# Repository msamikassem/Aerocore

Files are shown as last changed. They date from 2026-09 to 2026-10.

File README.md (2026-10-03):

# Aerocore — 3" Flight Controller

Aerocore is a flight controller for 3-inch FPV drones, built around an STM32F411 microcontroller and a BMI270 IMU. It handles IMU sensing, ESC motor control, USB configuration, and power regulation from a 4S LiPo on a single 4-layer board.

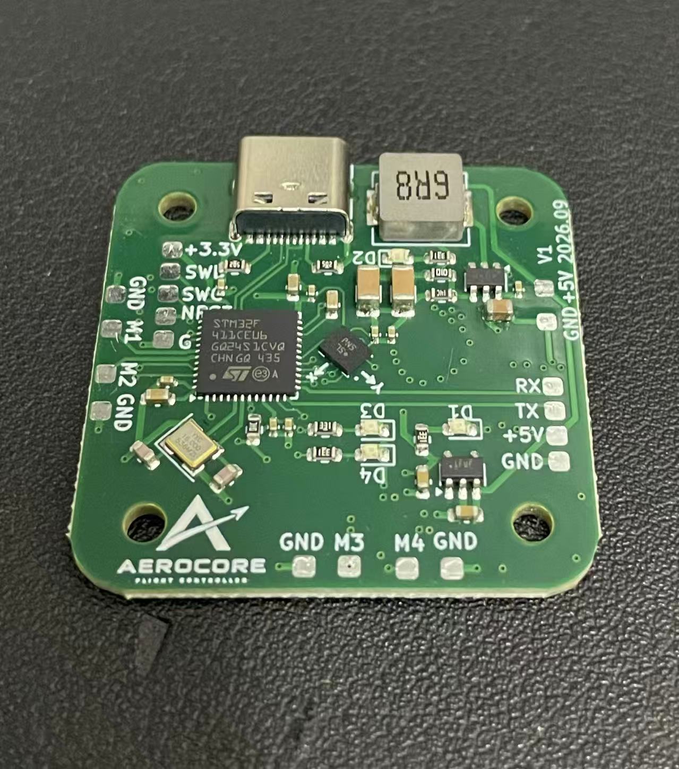
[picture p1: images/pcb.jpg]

## What it does

- Runs an STM32F411CEU6 (Cortex-M4, 100MHz) as the main flight computer
- BMI270 6-axis IMU over SPI for gyro/accel
- USB-C mainly for serial communication with a PC
- Powers itself from a 4S LiPo, steps down to 5V (buck) and 3.3V (LDO) on board
- Drives 4 ESCs via PWM 
- UART header for an ELRS receiver
- Dedicated ST-Link header for programming/debugging
- 2 status LEDs + 2 power LEDS (5v and 3v)

## Key specs

| | |
|---|---|
| MCU | STM32F411CEU6, 100MHz Cortex-M4, QFN48 |
| IMU | Bosch BMI270, SPI |
| Input power | 4S LiPo (up to 60A absolute max draw, 15A per motor) |
| Onboard rails | 5V (LMR51430 buck), 3.3V (TLV75533 LDO) |
| USB | USB-C, USB2.0 full-speed |
| Board | 4 layers, 36×36mm, 1.6mm thick |
| Stackup | JLC04161H-7628 (1oz outer / 0.5oz inner copper) |
| Mounting holes | 4× M2.5, 26.5×26.5mm spacing|

## Repo layout

```
hardware/                           -> PCB files
    kicad/                          -> the actual schematic + PCB source files (final version)
    Component/      
        Data_sheets/                -> Data sheets of chosen components 
        My_FootPrints.pretty/       -> FootPrints not avaliable on KiCAD
        Schematics/                 -> Schematics not avaliable on KiCAD
        3D part/                    -> Components' 3D model
    archive/                        -> PCB V1
    manufacturing/                  -> files needed by PCB manufacturer
        bom/                        -> bill of material
        cpl/                        -> component placement
        DRC/                        -> KiCAD Error and warning reports
    
firmware/                           -> flight firmware
docs/
    design-log                      -> PCB design decisions and difficulties
    specs                           -> PCB specifications  
```

## Status

- [X] Schematic design
- [X] PCB layout
- [X] Ordered from JLCPCB
- [X] Board assembled and bring-up tested
- [ ] Firmware
- [ ] First flight

## Tools used

- KiCad 7 for schematic + PCB

## License

MIT — see [LICENSE](LICENSE). Feel free to use any of this for your own projects; if you spot a mistake I haven't caught yet, I'd genuinely like to know.

## Author

Mohammed Kassem — built as a personal project. [msamikassem@gmail.com/ linkedin.com/in/msamikassem]

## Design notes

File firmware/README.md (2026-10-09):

# Firmware

Bare-metal firmware for the Aerocore flight controller using the STM32F411 and BMI270.

## Current Status

* STM32F411 project created.
* 16 MHz external crystal configured.
* PLL configured for 96 MHz system clock.
* APB1 configured to 48 MHz and APB2 to 96 MHz.
* PB3 LED tested at 96 MHz.
* ST-LINK working for flashing and debugging.
* SPI1 configured for the BMI270 (mode 0, 6 MHz).
* BMI270 CHIP_ID read successfully (0x24).
* BMI270 config file loaded.
* Accelerometer (±4g, 1600 Hz) and gyroscope (±250 dps, 3200 Hz) working.
* Raw and scaled (g and dps) values printed over USB-C.

## Planned Approach

* Bare-metal C to learn how the STM32 works at the register level.
* SPI1 for the BMI270.
* DMA for transferring data.
* TIM4 PWM for the 4 ESCs.
* USART2 for the ELRS receiver.
* USB-C for serial communication.
* Eventually add sensor fusion and basic flight control.

## Toolchain

* STM32CubeMX — used only to generate the initial project files.
* STM32CubeIDE — used to write, build, and debug the firmware.
* ARM GNU Toolchain — used to compile the firmware.
* ST-LINK — used to flash and debug the PCB.

## Tasks

**Clock**

* [x] Configure 16 MHz HSE
* [x] Configure 96 MHz PLL
* [x] Test clock using PB3 LED

**USB-C**

* [X] Configure USB
* [X] Test serial communication

**SPI / BMI270**

* [x] Configure SPI
* [x] Write SPI read/write functions
* [x] Load BMI270 config file
* [x] Read BMI270 data
* [x] Convert raw data to g and dps
* [X] Calibrate gyro offset
* [ ] Add DMA

**ESCs**

* [ ] Configure TIM4 PWM
* [ ] Test all 4 motors
* [ ] Try DShot later

**ELRS**

* [ ] Configure USART2
* [ ] Read CRSF data
* [ ] Decode channels

**Flight Control**

* [X] Sensor fusion
* [ ] Rate control
* [ ] Angle control
* [ ] Motor mixing

See [docs/DEVLOG.md](docs/DEVLOG.md) for the development log and the problems I ran into.

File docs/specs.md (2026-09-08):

# Technical Specs

Reference doc for the actual pin mapping, power tree, and stackup. Written mainly so I don't have to reopen KiCad every time I forget which pin does what.

## MCU pin mapping

| Function | Net | STM32F411 pin |
|---|---|---|
| SPI1 CS (IMU) | SPI1_CS | PA4 |
| SPI1 SCK (IMU) | SPI1_SCK | PA5 |
| SPI1 MISO (IMU) | SPI1_MISO | PA6 |
| SPI1 MOSI (IMU) | SPI1_MOSI | PA7 |
| IMU interrupt 1 | IMU_INT1 | PA1 |
| IMU interrupt 2 | IMU_INT2 | PB0 |
| HSE crystal in | HSE_IN | PH0 |
| HSE crystal out | HSE_OUT | PH1 |
| USB D- | USB_D- | PA11 |
| USB D+ | USB_D+ | PA12 |
| USART2 TX (ELRS) | USART2_TX | PA2 |
| USART2 RX (ELRS) | USART2_RX | PA3 |
| Motor 1 PWM | TIM4_CH1 | PB6 |
| Motor 2 PWM | TIM4_CH2 | PB7 |
| Motor 3 PWM | TIM4_CH3 | PB8 |
| Motor 4 PWM | TIM4_CH4 | PB9 |
| SWCLK (debug) | SWCLK | PA14 |
| SWDIO (debug) | SWDIO | PA13 |
| NRST | NRST | NRST pin, pulled up via 10k, switchable to GND for bootloader entry |
| BOOT0 | BOOT0 | Selected via SPDT switch, GND or 3.3V |
| Status LEDs | — | PB1, PB2, PB3, PB4 (one per LED, each with its own series resistor) |

Everything else (PC13/14/15, PA0, PA8-10, PA15, PB5, PB10, PB12-15) is currently unused and marked no-connect — left available for future expansion (e.g. a second UART, extra PWM outputs, etc.).

## Power tree
4S Lipo (battery input)
    -> ESC power pads x4
    -> LMR51430 > (5V) > TLV75533 > (3.3V) > MCU, IMU logic

- Buck converter feedback divider: R3 (100k, top) / R4 (13.7k, bottom), targets 4.98V output (0.6V reference × (100+13.7)/13.7).
- LDO input/output decoupling: 1µF ceramic on each side, per datasheet recommendation.
- USB VBUS is intentionally **not connected** to anything on the board, this avoids any interaction between USB host power and the battery rail when both happen to be connected at once. 

## Connectors

| Ref | Function | Pins |
|---|---|---|
| J2 | Battery input | +BATT, GND |
| J4, J6, J8, J10 | ESC power (×4) | +BATT, GND |
| J1, J5, J7, J9, J11 | ESC PWM signal (×4, one spare) | TIM4_CHx, GND |
| J12 | ELRS receiver (UART) | GND, +5V, USART2_TX, USART2_RX |
| J13 | Auxiliary solder pad header | — |
| J3 | USB-C | Full USB2.0 pinout, CC1/CC2 pulled down (5.1kΩ-class) for UFP detection, VBUS/SBU/shield unconnected |
| ST-Link header | Programming/debug | GND, NRST, SWCLK, SWDIO, 3.3V |

All the ESC/battery connectors (everything except J3) are bare copper pads meant for hand-soldering wires directly — not off-the-shelf connector parts, which is why they don't appear in the assembly BOM.

## PCB stackup

4-layer board, JLCPCB **JLC04161H-7628** profile, 1.6mm total thickness.

| Layer | Function | Copper |
|---|---|---|
| L1 (Top / F.Cu) | Signal + power | 1oz |
| L2 (In1.Cu) | Ground plane | 0.5oz |
| L3 (In2.Cu) | Signal + power | 0.5oz |
| L4 (Bottom / B.Cu) | Mixed: power stage components + GND pours | 1oz |

Board outline: 36×36mm. Mounting holes: 4× 2.7mm diameter (clearance for M2.5 screws), spaced 26.5×26.5mm

USB D+/D- differential pair: 0.2mm trace width, 0.45mm gap, routed on L1 referencing the L2 ground plane, targeting 90Ω differential impedance (validated against the real stackup dielectric values using JLCPCB's own impedance calculator, not a generic formula).

## Manufacturing settings used (JLCPCB)

- 4 layers, 1.6mm thickness, 1oz outer / 0.5oz inner copper
- Stackup: JLC04161H-7628
- Surface finish: chosen based on assembly method (HASL fine for machine-assembled fine-pitch parts with a proper stencil; would lean ENIG if hand-soldering)
- Assembly: Top

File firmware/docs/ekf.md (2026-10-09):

# Attitude EKF

Design notes for the attitude Extended Kalman Filter in `attitude_ekf.c` / `attitude_ekf.h`.
The code comments say what each line does. This document explains why it is built this way.

## Purpose

Estimate the roll and pitch angle of the drone from a BMI270 IMU (gyroscope + accelerometer).

* The **gyroscope** is smooth and fast, but its angle drifts when integrated.
* The **accelerometer** gives an absolute roll/pitch from gravity, but it is noisy and is fooled by any acceleration other than gravity (shaking, pushing, vibration).
* The EKF integrates the gyro (prediction) and uses the accelerometer to slowly correct the drift (correction).

Yaw is not estimated.

## Conventions

| Item | Convention |
|---|---|
| Body frame | X = forward, Y = right, Z = down |
| Level board | ax ~ 0, ay ~ 0, az ~ -1 g |
| Gyro units (EKF input) | rad/s |
| Accelerometer units (EKF input) | g (only the direction matters, except for the shake check) |
| Angles (EKF internal and output) | radians |
| Positive roll | right side down |
| Positive pitch | nose up |

`imu_to_body()` converts sensor axes to the body frame. The BMI270 reads az = +1 g when flat, so it flips Y and Z (a 180 degree rotation about X). It is applied to both the gyro and the accelerometer. If the board is mounted differently, only this function changes.

The driver outputs the gyro in deg/s. `main.c` multiplies by `DEG2RAD` before calling the filter, and by `RAD2DEG` when printing angles.

## State

```
x = [ phi, theta, b_phi, b_theta ]
```

| Index | Name | Meaning |
|---|---|---|
| 0 | `S_ROLL` | roll angle phi |
| 1 | `S_PITCH` | pitch angle theta |
| 2 | `S_BIAS_ROLL` | roll bias b_phi |
| 3 | `S_BIAS_PITCH` | pitch bias b_theta |

The 4x4 covariance `P` describes how uncertain each state is.

## Prediction step

Inputs: gyro p, q, r (rad/s) and dt (s).

1. Subtract the calibration offsets: `p = p_raw - offset[0]`, and the same for q and r.
2. Convert body rates to Euler angle rates:

```
phi_dot   = p + (q sin(phi) + r cos(phi)) tan(theta)
theta_dot = q cos(phi) - r sin(phi)
```

3. Integrate with Euler's method: `x = x + x_dot * dt`. The biases have zero derivative (slowly changing).
4. Wrap the angles to [-pi, pi].
5. Propagate the covariance: `P = F P F^T + Q`.

`F = I + (df/dx) dt`. The non-trivial entries are:

| Entry | Value |
|---|---|
| `F[roll][roll]` | `1 + (q cos(phi) - r sin(phi)) tan(theta) dt` |
| `F[roll][pitch]` | `(q sin(phi) + r cos(phi)) / cos^2(theta) dt` |
| `F[roll][bias_roll]` | `-dt` |
| `F[pitch][roll]` | `(-q sin(phi) - r cos(phi)) dt` |
| `F[pitch][pitch]` | `1` |
| `F[pitch][bias_pitch]` | `-dt` |
| bias rows | identity |

## Correction step

The accelerometer gives a direct measurement of the angles:

```
roll_acc  = atan2(-ay, -az)
pitch_acc = atan2(ax, sqrt(ay^2 + az^2))
```

The level trim (see below) is subtracted from both.

* Measurement `z = [roll_acc, pitch_acc]`, model `h(x) = [phi, theta]`, so `H = [[1 0 0 0],[0 1 0 0]]`.
* Innovation `y = z - h(x)`, wrapped to [-pi, pi].
* `S = H P H^T + R`, `K = P H^T S^-1`, `x = x + K y`, `P = (I - K H) P`.
* If `det(S)` is almost zero, the correction is skipped.

## Tuning values and why

| Parameter | Value | Reason |
|---|---|---|
| Initial P (roll, pitch) | 0.1 | About 18 degrees of uncertainty at startup, so the accelerometer is trusted at first |
| Initial P (biases) | 0.01 | Biases start near zero |
| Q (roll, pitch) | 1e-5 | Gyro integration noise |
| Q (biases) | 1e-7 | Biases change slowly, so they are predicted more reliably than the angles |
| R base | 3e-2 | Accelerometer noise. Raised from 3e-3 after shake tests (see Devlogs, problem 10) |

### Adaptive R (shake rejection)

R is multiplied by `r_scale = 1 + e^2 + ie^2`, capped at 50:

* `e = (|accel| - 1 g) / 0.02` becomes large when the accelerometer does not read 1 g.
* `ie = max(|y_roll|, |y_pitch|) / 0.17` becomes large when the accelerometer angle disagrees with the filter by more than about 10 degrees.

A larger R makes the filter trust the accelerometer less and follow the gyro more. The cap keeps the accelerometer from being ignored completely, so the filter can still recover.

The trade-off: a larger scale gives less error while shaking but slower recovery afterwards. The values 0.02, 0.17 and the cap of 50 are tuning numbers, found by testing, not derived.

## Calibration

### Gyro offsets

The gyro has a small fixed zero offset. It is measured while the drone is completely still:

1. `attitude_calibrate_start()`
2. `attitude_calibrate_add()` for each sample (about 3000 samples, roughly 2 s at 1600 Hz)
3. `attitude_calibrate_finish()` stores the average in `gyro_offset[]`

`attitude_init()` takes the stored offsets (from memory) as an argument, so calibration is optional at startup. The offsets are in rad/s and in the body frame (the calibration applies `imu_to_body()`).

These offsets are separate from the bias states in the EKF. The offsets are a fixed value measured at rest, and the bias states are meant to track slow changes.

### Level trim

A level drone can still read about 0.5 to 1.5 degrees because of mounting error and the accelerometer zero-g offset. `attitude_set_level_trim(att, roll_deg, pitch_deg)` stores the values the filter reads when level, and they are subtracted from the accelerometer angles inside `correct()`. It must be redone if the board is remounted.

## Timing

The filter needs the real time between samples. The BMI270 raises INT1 on every new sample (1600 Hz), and the interrupt handler measures the CPU cycles since the previous sample with the DWT counter: `dt = cycles / 96 MHz`. The counter is reset at the end of `bmi_int_init()`, so the first interval is a normal one.

The IMU interrupt (EXTI1) has priority 1 and the radio UART interrupt has priority 0. The UART interrupt can therefore run during the IMU handler's SPI read, so no radio bytes are lost (see `Radio.md`).

## Known limitations

* The bias states are not subtracted from the gyro rates in `predict()`, so they do not currently help. Only the calibration offsets are applied. `F` already contains the `-dt` terms for them, so the model and the prediction are not fully consistent.
* Pitch is wrapped to +-pi, but it should stay within +-pi/2. Near 90 degrees pitch, `tan(theta)` and `1/cos^2(theta)` blow up (the Euler angle singularity).
* `S` is computed as `H P + R`, which equals `H P H^T + R` only because H selects the first two states. It must be rewritten if H changes.
* The accelerometer cannot tell a sustained sideways acceleration from a tilt. The adaptive R reduces the effect, but does not remove it.
* Yaw is not estimated.
* Not yet tested in flight.

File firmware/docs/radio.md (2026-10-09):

# Radio Receiver (UART + CRSF)

Design notes for `uart.c` / `uart.h` and `crsf.c` / `crsf.h`.
The code comments say what each line does. This document explains how the pieces fit together and why.

## Overview

```
ELRS receiver --UART--> USART2 --byte--> RX interrupt --> CRSF parser --> 16 channels
                                                        
```

* `uart.c` receives bytes from the receiver (USART2).
* `crsf.c` collects the bytes into packets and unpacks the channel values.
* The main loop reads the channels when a new packet has been decoded.

## Hardware and UART settings

| Item | Value |
|---|---|
| Receiver output | CRSF over UART (ELRS receiver) |
| Pins | PA2 = USART2_TX, PA3 = USART2_RX (AF7) |
| Frame | 420000 baud, 8 data bits, no parity, 1 stop bit |
| USART2 clock | APB1 = 48 MHz (with the system clock at 96 MHz) |
| BRR | `(48000000 + 420000 / 2) / 420000 = 114` (about 421053 baud) |

The baud rate depends on the clock of the bus the USART is on. USART2 is on APB1, which is not the CPU clock. The value in `uart.c` (`SYS_CLK`) must match the real APB1 clock. It can be checked at run time with `HAL_RCC_GetPCLK1Freq()`. If the clock setup in `clock_96MHz()` changes, update `SYS_CLK`.

`UART2_init()` must be called after `usb_init()` (which sets up the 96 MHz clock).

## CRSF packet format

Every packet:

| Byte | Content |
|---|---|
| 0 | Address (`CRSF_ADDRESS`, 0xC8 for packets to the flight controller) |
| 1 | Length (type + payload + CRC) |
| 2 | Type |
| 3 .. n-1 | Payload |
| n | CRC |

The total size is `length + 2` bytes. The parser only handles type 0x16 (RC_CHANNELS_PACKED) with a length of 24:

* 22 bytes of payload, holding 16 channels of 11 bits each (176 bits), packed one after the other with no gaps.
* 1 byte of CRC.

Other packet types, such as link statistics, arrive too. They are collected and ignored. That is why the byte count (about 6500 per second) is higher than 246 packets x 26 bytes.

### Channel values

* Each channel is 11 bits (0 to 2047).
* The usual CRSF range is about 172 to 1811, with the center at 992. The values measured on this radio: centered sticks read 992, low throttle reads 174. The exact end points still have to be checked for each channel.
* Channel order is set in the radio. The defaults used here are 1 = roll, 2 = pitch, 3 = throttle, 4 = yaw.

## Parser (`CRSF_process_byte`)

The parser is a small state machine. It receives one byte per call and remembers its state in `static` variables (`packet[]`, `index`, `length`).

1. `index == 0`: wait for the address byte. Anything else is ignored. This is also how the parser re-synchronizes after an error.
2. `index == 1`: read the length. If it is below 2 or above 62, the packet is rejected and the parser starts again.
3. Otherwise, store bytes until `index == length + 2`.
4. If the type is 0x16 and the length is 24, decode the channels and return 1. Any other type is dropped and the parser starts again.

It returns 1 only on the last byte of a good RC packet, so a return value of 1 means "new channel values are available".

### Decoding

For channel `i`, the first bit is at `i * 11`. An 11-bit value can cross into a third byte, so three bytes are read as one 24-bit number, shifted right by `bit_offset` (0 to 7), and masked with `0x07FF`.

## Receiving: interrupt, not polling

A byte arrives every 24 us (10 bits at 420000 baud), and the USART holds only one byte. If a byte is not read before the next one arrives, it is overwritten (an overrun), and a packet needs every byte.

Reading in the main loop does not work once the loop does anything slow, such as the EKF update or the IMU read. So the bytes are received in `USART2_IRQHandler`:

```c
volatile uint8_t rc_ready = 0;       /* defined once, in uart.c */

void USART2_IRQHandler(void)
{
    if (USART2->SR & (USART_SR_RXNE | USART_SR_ORE))
    {
        uint8_t b = (uint8_t)USART2->DR;     /* reading DR clears the flags */

        if (CRSF_process_byte(b))
        {
            rc_ready = 1;
        }
    }
}
```

* The handler is tiny (about 1 to 2 us), so it takes very little CPU time.
* `UART2_read()` (polling) must not be used together with the interrupt, because the handler empties the data register first.
* `rc_ready` is declared `extern` in `uart.h`, so only one file defines it.

### Interrupt priorities

| Interrupt | Priority | Reason |
|---|---|---|
| USART2 (radio) | 0 | A radio byte must never wait for another handler |
| EXTI1 (IMU data ready) | 1 | The IMU handler reads the sensor over SPI (tens of microseconds), which is longer than one byte time |

With the UART at a higher priority, it can interrupt the IMU handler, so no byte is lost.

## Using the channels in the main loop

```c
if (rc_ready)
{
    __disable_irq();
    rc_ready = 0;
    roll_cmd     = CRSF_get_channel(1);
    pitch_cmd    = CRSF_get_channel(2);
    throttle_cmd = CRSF_get_channel(3);
    yaw_cmd      = CRSF_get_channel(4);
    __enable_irq();
}
```

The interrupts are disabled for the copy so a new packet cannot change the values halfway through.

### Throttle mapping

CRSF 172 to 1811 is clamped and mapped to 1000 to 2000 us:

```
t = clamp(throttle, 172, 1811)
throttle_us = 1000 + (t - 172) * 1000 / (1811 - 172)
```

## Link loss detection

`rc_ready` cannot show a lost link, because it is cleared after every packet and is 0 for most of the time between packets (about 4 ms at 250 Hz).

The approach is a timeout:

* The handler stores the time of the last decoded RC packet: `rc_last_tick = HAL_GetTick()`.
* The main loop treats the link as lost if no RC packet has arrived for more than a timeout (for example 500 ms): `(HAL_GetTick() - rc_last_tick) >= timeout`.
* On a lost link, the failsafe applies (throttle to minimum, motors off).

This only works if the ELRS receiver stops sending RC packets when the link is lost. If it is configured to send fixed failsafe channel values instead, the packets never stop. The failsafe mode must be set accordingly in the ELRS configuration.

## Known limitations

* No CRC check. A corrupted packet with the right length and type would be decoded. The CRSF CRC is a CRC-8 with polynomial 0xD5 over the type and payload.
* Only the RC channels packet is decoded. Link statistics (signal strength, link quality) are ignored.
* Only the receive direction is used. Nothing is sent back to the receiver (no telemetry).
* The value of `CRSF_ADDRESS` (0xC8) is the usual one for this packet direction.
* Failsafe depends on the receiver settings (see above).
* The PWM output code (`pwm.c`) has to be checked against the current clock before connecting an ESC.

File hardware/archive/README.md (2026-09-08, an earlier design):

# Archive

`v1_Aerocore.kicad_pcb` is the first PCB layout attempt — kept here for reference, not used for manufacturing.

This version had the battery power plane split into disconnected copper islands and severe current-path bottlenecks (down to ~0.4mm wide in places, where 15A per motor really needs closer to 8mm on 1oz copper). See [../../docs/design-log.md](../../docs/design-log.md) for the full story of what was wrong and how I found it.

The schematic didn't change between v1 and v2 — only the PCB layout was redone, so there's only one schematic file in `hardware/kicad/`.

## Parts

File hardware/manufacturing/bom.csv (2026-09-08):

Comment | Designator | Footprint | LCSC Part #
10u | C1 | Capacitor_SMD:C_0603_1608Metric | C1713
1u | C2, C3, C18 | Capacitor_SMD:C_0603_1608Metric | C1592
100n | C4, C7, C8, C11, C13, C14, C16, C17 | Capacitor_SMD:C_0402_1005Metric | C1525
22u | C5, C6 | Capacitor_SMD:C_1206_3216Metric | C1859
4.7u | C9, C15 | Capacitor_SMD:C_0603_1608Metric | C1705
10p | C10, C12 | Capacitor_SMD:C_0603_1608Metric | C1634
LED | D1, D2, D3, D4 | LED_SMD:LED_0603_1608Metric | C2288
TYPE-C-31-M-12 | J3 | Connector_USB:USB_C_Receptacle_G-Switch_GT-USB-7010ASV | C165948
6.8u | L1 | Inductor_SMD:L_Sunlord_MWSA0603S | C408449
5K | R1, R2 | Resistor_SMD:R_0603_1608Metric | C166926
100k | R3 | Resistor_SMD:R_0603_1608Metric | C14675
13.7k | R4 | Resistor_SMD:R_0603_1608Metric | C22793
330 | R5, R6, R8, R9 | Resistor_SMD:R_0603_1608Metric | C49254170
10k | R7 | Resistor_SMD:R_0603_1608Metric | C25804
LMR51430 | U1 | Package_TO_SOT_SMD:SOT-23-6 | C5185863
TLV75533PDBV | U2 | Package_TO_SOT_SMD:SOT-23-5 | C404027
BMI270 | U3 | Custom:XDCR_BMI270 | C2836813
STM32F411CEU6 | U4 | Package_DFN_QFN:QFN-48-1EP_7x7mm_P0.5mm_EP5.6x5.6mm | C60420
16MHZ | Y1 | Crystal:Crystal_SMD_3225-4Pin_3.2x2.5mm | C112972

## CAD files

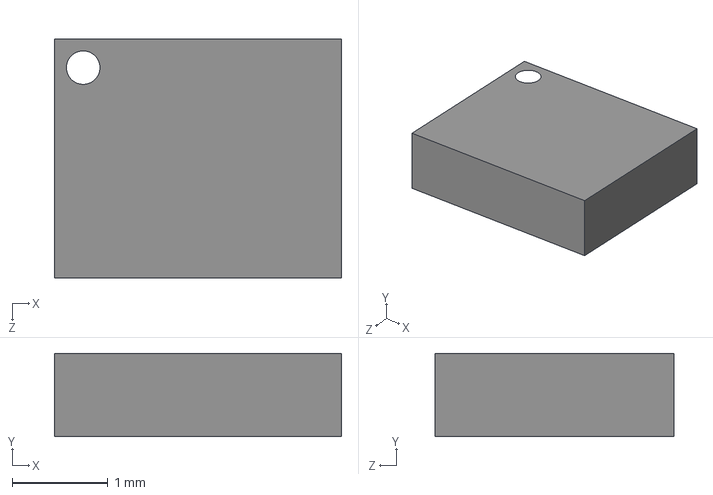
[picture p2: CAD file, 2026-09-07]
hardware/Components/3D Part/BMI270.step
3.00 x 0.87 x 2.50 mm

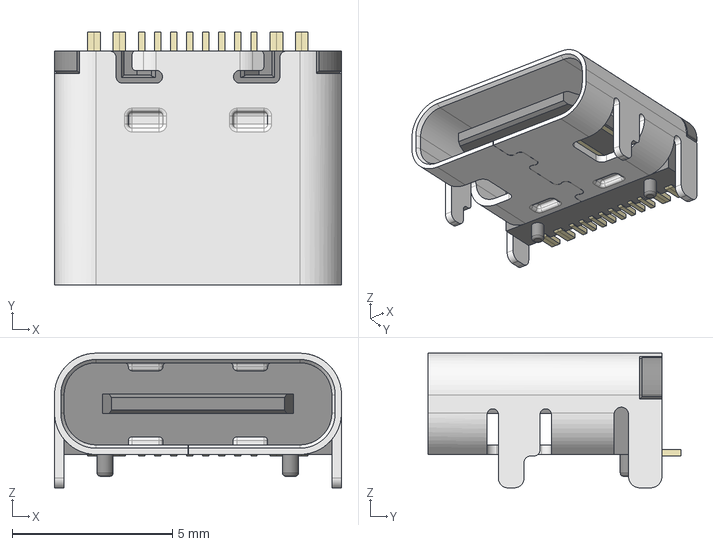
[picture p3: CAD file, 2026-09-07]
hardware/Components/3D Part/HRO_TYPE-C-31-M-12.step
8.95 x 7.90 x 4.20 mm

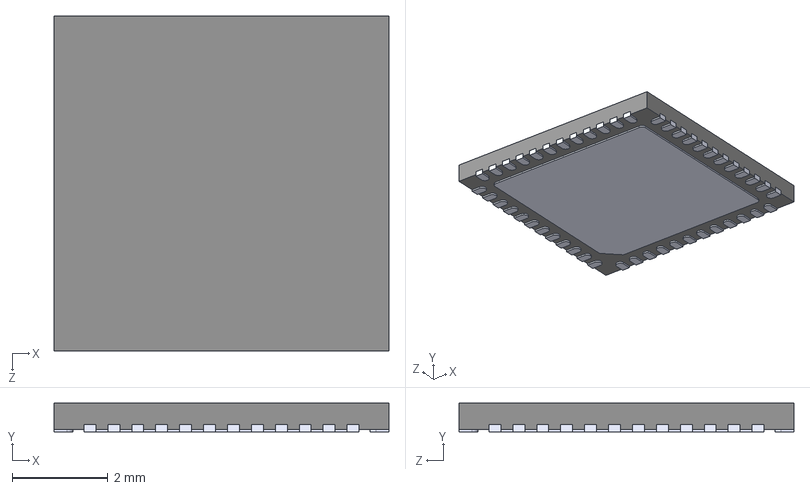
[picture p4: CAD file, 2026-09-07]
hardware/Components/3D Part/STM32F411CEU6--3DModel-STEP-56544.STEP
7.00 x 0.6 x 7.00 mm

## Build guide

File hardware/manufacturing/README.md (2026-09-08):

# Manufacturing files

These are the files actually used to order the board from JLCPCB.

- `bom.csv` — Bill of materials. Only lists real placeable parts (things with an LCSC part number).
- `cpl.csv` — component position file.
- `DRC.rpt` — Design rule check report from KiCad before ordering. 4 real "error" severity items (all on the USB-C connector's mechanical mounting holes) plus some cosmetic silkscreen warnings, all reviewed and accepted/fixed before ordering.

Gerbers aren't included here since they're a direct export of the PCB file in `hardware/kicad/`, regenerate with **File>Fabrication Outputs>Gerbers** in KiCAD.

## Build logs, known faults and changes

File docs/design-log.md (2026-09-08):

# Design Log

This is a rough chronological writeup of how this board actually got built, including the stuff that went wrong. I think that's the more useful part to write down, honestly, the schematic and PCB files show what I ended up with, but not how many times I almost shipped something broken.

## Why I started this

I wanted a flight controller that I actually understood, top to bottom, instead of just buying one off the shelf. I read enough about 3" quads to know roughly what a Flight controller needs to do (IMU, MCU, ESC outputs, receiver link), so I figured designing one myself was a good way to actually learn PCB design and embedded systems properly rather than just reading about it.

## Component choices

- **STM32F411CEU6** — Cortex-M4 at 100MHz, cheap, well documented, so there's plenty of reference material if I get stuck.
- **BMI270** — modern 6-axis IMU,cheap, SPI interface, low noise. I only use the main SPI interface (SDO/SDX/SCX/CSB), the auxiliary SPI/OIS pins (ASDX, ASCX, OCSB, OSDO) aren't used since I'm not attaching an external magnetometer, so those are marked no-connect.
- **LMR51430** buck converter for the 5V rail, **TLV75533** LDO for 3.3V off the 5V rail rather than straight off the battery,simpler to design and the LDO doesn't need to drop much voltage that way.
- USB-C instead of micro-USB, mostly because it's 2024+ and there's no excuse not to at this point.

## Mistake #1: crystal load capacitors

Early on I had my 16MHz crystal's load caps (C9/C10 at the time) set to **4.7µF**. Turns out I'd basically copy-pasted the value from a decoupling cap elsewhere in the BOM without thinking about it. Load caps for a crystal oscillator need to be in the **picofarad** range, not microfarad. If I'd sent that to fab as is, the oscillator simply wouldn't start, and the whole board would be dead on arrival with no obvious reason why from just looking at it. Caught this before ordering and fixed it to 10pF, which is a safe standard value for a 16MHz crystal in this kind of layout.

Lesson: double check *every* passive value that isn't obviously self-checking, especially anything copy-pasted between components that look similar in the schematic.

## Mistake #2: the first PCB layout (the big one)

This is the part I think is most worth documenting.

I have a 4S LiPo feeding this board, and each of the 4 motors can pull up to 15A, so worst case the input rail sees 60A. My plan was to just make the entire bottom copper layer a big `+BATT` zone and let the copper handle it. Sounded reasonable at the time.

After actually checking the filled copper geometry, I found two real probleRedesign PCB layout to fix power distribution issuesms:

1. **The battery plane was split into two disconnected islands.** My buck converter sat in the middle of the board, between the battery input and the ESC connectors, and its own footprint clearances plus a couple of GND cutouts ended up slicing the `+BATT` pour into two separate pieces. The regulator's own VIN pins were sitting on an island bridged back to the main plane by about a 0.3mm trace. That's fine for the regulator's own (small) current draw, but it meant the "big 60A plane" wasn't actually one continuous plane at all.

2. **Severe pinch points between the battery input and the ESC pads.** I measured the actual minimum copper width along the path from the battery connector to each ESC power pad and got numbers like 0.36mm–1.77mm in places. For reference, using the standard IPC-2221 trace sizing rule, you need roughly **8mm of width** on 1oz copper to carry 15A continuously without excessive heating. A 0.4mm neck is nowhere close, and it would've meant serious local heating right where a battery is plugged into a device with spinning props.

Neither of these show up as an obvious visual problem when you're just looking at "yeah there's a big copper zone there", you actually have to check the result and think about the current path, not just the outline.

Given how central the layout mistake was (the whole middle of the board was in the way of the power path), I decided patching it wasn't worth it and redid the layout from scratch, this time placing the battery input and ESC power pads first and building the power plane around them then placing the regulator on **TOP** layer.

## Redesign (v2 — what's actually in `hardware/kicad/` now)

- Rechecked the filled copper after placement and got like a single, fully connected `+BATT` region, with the narrowest points now in the 3–10mm range depending on which ESC, a big improvement, though I'd still like the tightest ones a bit wider if I revise this again.

- Decided to place the buck converter and LDO on the top layer, allowing the bottom layer to be only a region of `+BATT` and `GND`.

- Soldering pads instead of pin headers for the ST-LINK connector. I was running out of space! This actually has the added feature of not having ugly looking pins sticking out, meaning I could solder and desolder connections any time.

## Bottom Layer /L4

Made three 'islands' the main one being `+BATT` and three `GND` regions, two at the corners connecting each ESC's ground and a small zone around the `GND` of the Lipo soldering Pad. 

## Stitching (Vias)

I utilized the method of stitching, using several vias in a close region, to safely conduct the high current (60A worst case scenario). Nothing random was made here, using the KiCAD via size calculator, I knew a 0.6mm diameter via is capable of an estimated ampacity of about 4A. I made 18 vias inside each GND zone, and made sure they were close to the soldering pads.

## USB differential pair

I wanted the USB D+/D- pair impedance-matched to 90Ω since that's the USB2.0 target. Rather than trust a rough hand calculation, I used JLCPCB's own impedance calculator against their actual **JLC04161H-7628** stackup, which gave me the trace width and gap to use. This matters because a stackup's exact dielectric thickness changes the required geometry a lot, and a generic formula without the real numbers can be off by a meaningful margin.

## DRC and manufacturing file issues

Running an actual DRC check turned up a few things:

- 4 hole-clearance flags on the USB-C connector, between its mechanical alignment holes and its own ground pads. These turned out to be inherent to that specific connector's footprint accepted these as known and moved on rather than trying to force a fix that isn't really a fix.
- A couple of cosmetic silkscreen issues, fixed those since they're easy and free.

Separately from DRC, my exported BOM and CPL (pick-and-place) files both got rejected by JLCPCB's uploader on the first try:

- The BOM's header row had one more column (`DNP`) than the actual data rows did, which shifted every part's LCSC number into the wrong column as far as the parser was concerned.

## Current status

Board is ordered from JLCPCB (4-layer, HASL decision made based on assembly method, both sides populated since the power stage lives on the bottom layer). Once it's back, next steps are bring-up testing (power rails first, then IMU communication) before touching flight firmware.

## Things I'd do differently next time

- Check filled copper geometry for any high-current net considering a layout "done," not as an afterthought.
- Pick a standard mounting hole pattern from the start instead of placing holes arbitrarily and discovering the mismatch later.
- Keep passive component values in a spreadsheet with datasheet references while designing, instead of trusting memory/copy paste for things like crystal load caps.

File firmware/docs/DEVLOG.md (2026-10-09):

# Development Log

Problems I ran into while building the Aerocore firmware and how I solved them.

## BMI270 Bring-up

### 1. CHIP_ID always read 0x00

**Date:** 10/04/2026

**Problem:**

* Reading the CHIP_ID register (0x00) over SPI always returned 0x00.
* The expected value for the BMI270 is 0x24.

**Cause:**

* On SPI reads, the BMI270 sends one dummy byte before the real data.
* My code sent the address and then read only one byte, so I was reading the dummy byte.

**Fix:**

* Read two bytes after the address and throw away the first one.
* Wrapped this in a read function so every register read handles the dummy byte the same way.

**Result:** CHIP_ID = 0x24.

**What I learned:**

* Always check the datasheet for how the SPI read works, not just the register address.
* A value of exactly 0x00 can be the dummy byte, not a broken connection.

**Note:** I changed the dummy byte, the SPI clock and the GPIO speed (problems 2 and 3) at the same time, so I did not test which one alone fixed the 0x00. The dummy byte is the one that explains getting exactly 0x00.

### 2. SPI clock was too fast

**Date:** 10/04/2026

**Problem:**

* The prescaler was set to 0, which divides the clock by 2.
* APB2 runs at 96 MHz, so SPI1 ran at 48 MHz.
* The BMI270 supports a maximum of 10 MHz.

**Fix:**

* Changed the prescaler value to 3 (divide by 16), which gives 6 MHz.

**What I learned:**

* The BR bits in SPI_CR1 are not the divider itself: 0 = /2, 1 = /4, 2 = /8, 3 = /16.
* Always compare the SPI clock with the maximum in the sensor datasheet.

### 3. GPIO speed and switching the BMI270 to SPI

**Date:** 10/04/2026

**Problem:**

* The SPI pins were left at the default low output speed, so the clock and data edges were slow.
* The BMI270 starts in I2C mode and only switches to SPI after a rising edge on CS. In my code that edge only happened by accident.

**Fix:**

* Set PA4 to PA7 to very high speed in OSPEEDR.
* Added a dummy read of register 0x7F before the first real read, so CS goes low and then high on purpose.

**What I learned:**

* Output speed matters even for "slow" signals like a few MHz SPI.
* Some sensors choose their interface from what happens on the CS pin after power up.

### 4. Accelerometer and gyroscope data were all zero

**Date:** 10/04/2026

**Problem:**

* Setting the config registers (ACC_CONF, ACC_RANGE, GYR_CONF, GYR_RANGE, PWR_CTRL) worked and they read back correctly.
* The accelerometer and gyroscope values were still all zero.

**Cause:**

* The BMI270 needs an 8 KB configuration file uploaded after every power up or reset.
* Without it the sensor data stays at zero.

**Fix:**

* Added the Bosch configuration file (from the official BMI270 SensorAPI on GitHub) as `bmi_config.c`.
* Wrote `bmi_load_config()` to send it in 32 byte chunks, setting the target address in INIT_ADDR_0 and INIT_ADDR_1 before each chunk.
* Checked INTERNAL_STATUS (0x21): the lower 4 bits read 1 when the upload worked.

**Result:**

* Accelerometer Z read about 1 g (8192 LSB/g) when the board was flat.
* Gyroscope read close to zero when the board was still.

**What I learned:**

* A register reading back correctly only proves the write worked, not that the sensor is running.
* Some sensors need firmware or a config file loaded at startup.

### 5. Printing float values

**Date:** 10/04/2026

**Problem:**

* Printing the converted values (g and dps) with the float format did not work with the default newlib-nano settings.

**Fix:**

* Printed milli-units as integers instead (mg and mdps), by multiplying by 1000 and casting to int.
* The other option is to enable "Use float with printf from newlib-nano" in the project settings, at the cost of a bigger program.

**Update (10/09/2026):**

* I could not find that setting in my CubeIDE version.
* Instead I added `__asm__(".global _printf_float");` at the top of `usb_comm.c`. This forces the linker to include the float part of printf, the same as the `-u _printf_float` linker flag.
* `usb_printf("%.2f")` now prints correctly.

**What I learned:**

* Printing floats is not free on small microcontrollers.
* The same linker flag can be set from code if the IDE menu is not where the guide says.

## Interrupt-driven Sampling

### 6. Getting an exact dt for the EKF

**Date:** 10/09/2026

**Problem:**

* The EKF integrates `rate * dt`, so dt must be the real time between two IMU samples.
* Reading the IMU in a loop gives a dt that depends on how long the loop takes.

**Fix:**

* Set the BMI270 INT1 pin as a data-ready output and connected it to PA1 (EXTI1, rising edge).
* The interrupt handler `EXTI1_IRQHandler` (in `bmi.c`) reads the accelerometer and gyroscope and sets `imu_ready = 1`.
* It also stores the number of CPU cycles since the previous sample in `imu_cycles` (from the DWT cycle counter) and then resets the counter. `dt = imu_cycles / 96 MHz`.
* `dwt_init()` lives in `clk_speed.c` and must be called before `bmi_init()`.
* The main loop checks `imu_ready`, copies the data with interrupts briefly disabled, and runs the EKF once per sample.
* Changed the gyroscope output rate from 3200 Hz to 1600 Hz so every interrupt brings fresh data from both sensors.

**Result:**

* Timestamps from `HAL_GetTick()` confirmed one sample about every 0.625 ms (1600 Hz).

**What I learned:**

* An interrupt handler cannot return a value, so it writes to `volatile` globals and a flag, and the main loop polls the flag.
* `volatile` makes sure the main loop really re-reads the flag from memory instead of using an old copy.
* A disabled interrupt is delayed, not lost, and the cycle counter keeps counting, so the delay does not break dt.

### 7. First dt was huge, and duplicate definitions

**Date:** 10/09/2026

**Problem:**

* The first interval included the whole `bmi_init()` (config upload and delays, about 0.2 s), because the counter started in `dwt_init()`.
* If INT1 is already high when the interrupt is enabled, no rising edge is seen and no interrupt ever fires.
* The build failed with "redefinition of imu_ready": an old copy of the variables and handler was still in `bmi.c`.

**Fix:**

* At the end of `bmi_int_init()`: read accel and gyro once to clear waiting data, clear `EXTI->PR`, enable the interrupt, then set `DWT->CYCCNT = 0`.
* Used a `DT_MAX` check (skip any sample with dt above 0.1 s) while testing. The final `main.c` does not need it, because the counter is reset at the end of `bmi_int_init()`.
* Deleted the old definitions so each variable and the handler exist only once.

**What I learned:**

* An edge-triggered interrupt needs the line to go low first.
* Search the project for a name when the compiler reports a redefinition.

## Attitude EKF

### 8. Roll read about 180 degrees when level

**Date:** 10/09/2026

**Problem:**

* The EKF assumes Z points down, so a level board reads az = -1 g.
* The BMI270 reads az = +1 g when flat, so roll came out near 178 degrees.

**Fix:**

* Changed `imu_to_body()` to flip Y and Z (a 180 degree rotation about X). It is applied to both the gyro and the accelerometer.

**Result:**

* Level now reads roll about -1.5 degrees, pitch about 1 degree.

**What I learned:**

* Flipping only one axis makes a mirror image (left-handed frame). Flip two axes to get a real rotation.
* Check the direction with tilt tests (right side down gives positive roll, nose up gives positive pitch).

### 9. Small angle offset at rest

**Date:** 10/09/2026

**Problem:**

* A level board still read about 1 degree on both axes, and the value changed with the surface it sat on (-1.47 / 0.99 on one, about -1.0 / 0.5 on another).

**Cause:**

* Mounting error of the flight controller, a small accelerometer zero-g offset and surfaces that are not perfectly level.

**Fix:**

* Added `attitude_set_level_trim(att, roll_deg, pitch_deg)`. The trim is subtracted from the accelerometer angles inside `correct()`, so the filter state itself is level-referenced.
* The two values are measured once while the drone is on a surface I trust, and must be redone after remounting the board.

**What I learned:**

* A 0.5 to 1.5 degree static error is normal, and a flight controller removes it with a level calibration.

### 10. Shaking the drone corrupts the angle

**Date:** 10/09/2026

**Problem:**

* Shaking the drone on the ground, mostly along Y, moved the estimated roll a lot (about -18 degrees with the first version).

**Cause:**

* The accelerometer cannot tell a sideways push from a tilt. During the shaking `acc_roll` swung between about 12 and 49 degrees while the board stayed on the ground.
* Checked the gyro: at rest it is within about 0.3 dps with no steady bias, so the stored offsets are fine, and the gyro was not the cause.

**Fix:**

* The measurement noise R is now scaled by `r_scale = 1 + e^2 + ie^2`, capped at 50:
  * `e` grows when the accelerometer magnitude is not 1 g.
  * `ie` grows when the accelerometer angle disagrees with the filter angle.
* Base R raised from 3e-3 to 3e-2.
* Gyroscope range changed from 250 dps to 2000 dps, so fast rotations do not saturate the sensor.

**Result:**

* The worst shake test dropped from -26 degrees to about 7 degrees on roll, with pitch under 1 degree.
* A timestamped capture (1 ms resolution) showed roll swinging about +-8 degrees during the shaking, and the recovery after stopping looked to be under a second.

**What I learned:**

* The first attempt (only checking the magnitude) did nothing for sideways pushes, since they barely change the total magnitude, and one version made the result worse (-26 degrees).
* More distrust of the accelerometer means less error while shaking but slower recovery afterwards. It is a trade-off to tune.
* Do not assume the print rate. I misjudged the recovery time because I guessed how often lines were printed. Print a timestamp with the data.
* Hand shaking on the ground is harsher than flight. For real flight, motor vibration will be the bigger accelerometer problem.

## Radio Receiver (UART + CRSF)

### 11. Radio channels printed nothing once the EKF was in the program

**Date:** 10/09/2026

**Problem:**

* An older program with only the radio worked (UART + CRSF, 16 MHz clock).
* After combining it with the EKF and the 96 MHz clock, nothing printed.

**Cause (several faults together):**

* `UART2_init()` was never called. The line `void UART2_init(void);` inside `main()` is only a declaration.
* The baud rate was calculated for 16 MHz. After `clock_96MHz()`, USART2 runs from APB1 at 48 MHz, so the real baud rate was about three times too high.
* The init order was wrong: the UART must be set up after the clock is final.
* The main loop read one UART byte per IMU sample (1600 per second), but about 6500 bytes per second arrive (one every 24 us). The USART holds one byte, so the others were overwritten, and a CRSF packet needs all of its bytes in order.
* `UART2_read()` blocks until a byte arrives, which also stalled the EKF.
* Once the receive interrupt was on, no function named `USART2_IRQHandler` existed in the project, so the first byte would hang the program in the default handler. After adding it, `UART2_read()` could not be used at the same time, because the handler empties the data register first.

**Fix:**

* Removed the stray declarations and called `UART2_init()` after `usb_init()`.
* Set `SYS_CLK` in `uart.c` to 48 MHz, which gives BRR = 114 (about 421053 baud).
* Receive bytes in `USART2_IRQHandler`: it feeds each byte to `CRSF_process_byte()` and sets `rc_ready` when a full RC packet has been decoded. The main loop only checks `rc_ready`.
* USART2 interrupt priority 0, IMU interrupt (EXTI1) priority 1, so a radio byte is never lost while the IMU handler reads the sensor over SPI.

**Result:**

* A test program printed the real values: `pclk1 = 48000000`, `brr = 114`.
* About 3270 bytes and 123 RC packets every half second (about 246 packets per second), with the error counter staying at 4 after startup.
* Channels read 992 for the centered sticks and 174 for low throttle.

**What I learned:**

* A function declaration is not a call.
* Peripheral clocks change when the system clock changes. Print the real clock (`HAL_RCC_GetPCLK1Freq()`) instead of assuming it.
* A one-byte receiver needs an interrupt (or DMA) as soon as the loop does anything slow.
* Counters (bytes, errors, packets) printed together show quickly if the fault is wiring, baud rate or parsing.
* Changing several things at once means I cannot say which one fixed it.

### 12. Build errors when moving the handler into uart.c

**Date:** 10/09/2026

**Problem:**

* "implicit declaration of function CRSF_process_byte" in `uart.c`.
* Then "multiple definition of rc_ready" from the linker.

**Cause:**

* `uart.c` did not include `crsf.h`.
* `rc_ready` was defined (not just declared) in `uart.h`, so every file including the header got its own copy.

**Fix:**

* Added `#include "crsf.h"` to `uart.c`.
* The header only has `extern volatile uint8_t rc_ready;`, and the one definition (with the value) is in `uart.c`.

**What I learned:**

* A header declares (`extern`), and exactly one `.c` file defines.

### 13. CRSF channel range is not 0 to 2047

**Date:** 10/09/2026

**Problem:**

* The old throttle mapping used 0 to 2047, but the printed minimum throttle was 174.

**Fix:**

* Clamp the value to 172 to 1811 and map that range to 1000 to 2000 us. Without it, minimum throttle gives about 1085 us instead of 1000 us, so the motors would idle slightly on.
* The min and max are the usual CRSF values. They still have to be checked against my own radio by moving the sticks to the ends.

**What I learned:**

* Read the real numbers from the radio before choosing a mapping.

### 14. Detecting a lost radio link

**Date:** 10/09/2026

**Problem:**

* `rc_ready` is cleared after every packet, so `rc_ready == 0` is the normal state between packets (about 4 ms at 250 Hz). It cannot show a lost link.

**Fix:**

* Store the time of the last decoded RC packet (`rc_last_tick`) and compare it with `HAL_GetTick()`. If the packet is older than a timeout (500 ms to start with), the link is treated as lost and the failsafe applies.

**What I learned:**

* A flag says "something happened". A lost link needs a timestamp and a timeout.
* The timeout only works if the ELRS receiver stops sending RC packets when the link is lost. If it is set to send fixed failsafe values, the packets never stop.

## Checked Results

| Test | Result |
|---|---|
| CHIP_ID | 0x24 |
| INTERNAL_STATUS after config upload | 1 |
| Accelerometer, board flat | Z about 1006 mg, X about 35 mg, Y about 3 mg |
| Gyroscope, board still | within about +-0.7 dps, average near 0 |
| Sample rate (timestamps) | about 1600 Hz (0.625 ms between samples) |
| Gyroscope calibrated, board still | within about +-0.3 dps on all axes, average near 0 |
| EKF, board level (before trim) | roll about -1.5 deg, pitch about 1 deg |
| EKF, hard shake on ground | roll swing about +-8 deg, pitch under 1 deg |
| USART2 clock / baud rate | PCLK1 = 48 MHz, BRR = 114 (about 421053 baud) |
| Radio receive rate | about 246 RC packets per second, about 6500 bytes per second |
| Radio sticks centered / throttle low | 992 / 174 |

The small accelerometer X offset and the gyroscope noise are normal for an IMU at rest.

## Open Issues / To Do

* The bias states (`x[2]`, `x[3]`) are not subtracted from the gyro in `predict()`, so the filter cannot track gyro drift on its own. Only the startup calibration offsets are used.
* Pitch is wrapped to +-pi, but it should be limited to +-pi/2 (Euler angle singularity at 90 degrees).
* `S = H P H^T + R` is computed as `H P + R`. It works only because H selects the first two states, and it must change if H changes.
* Mount the flight controller on foam or rubber and check the BMI270 filter bandwidth settings, since motor vibration will affect the accelerometer.
* Store the gyro offsets and the level trim in flash so they survive power cycles.
* Add the CRC check to the CRSF parser. Right now a corrupted packet with the right length and type would be decoded.
* Add the radio link timeout (problem 14) to `main.c` and set the ELRS failsafe mode so that RC packets stop when the link is lost.
* Check the real minimum and maximum of every channel on my radio (CRSF_MIN and CRSF_MAX are the usual values).
* Check `pwm.c`: it was written for the 16 MHz clock, and TIM4 sits on APB1, which runs at 48 MHz now, so the ESC pulse widths must be recalculated before connecting a motor.
* Measure the EKF update time and count IMU overruns (the main loop must finish a sample before the next interrupt).
* Build with optimization (-O2 or the Release configuration).
* Test the filter in flight.

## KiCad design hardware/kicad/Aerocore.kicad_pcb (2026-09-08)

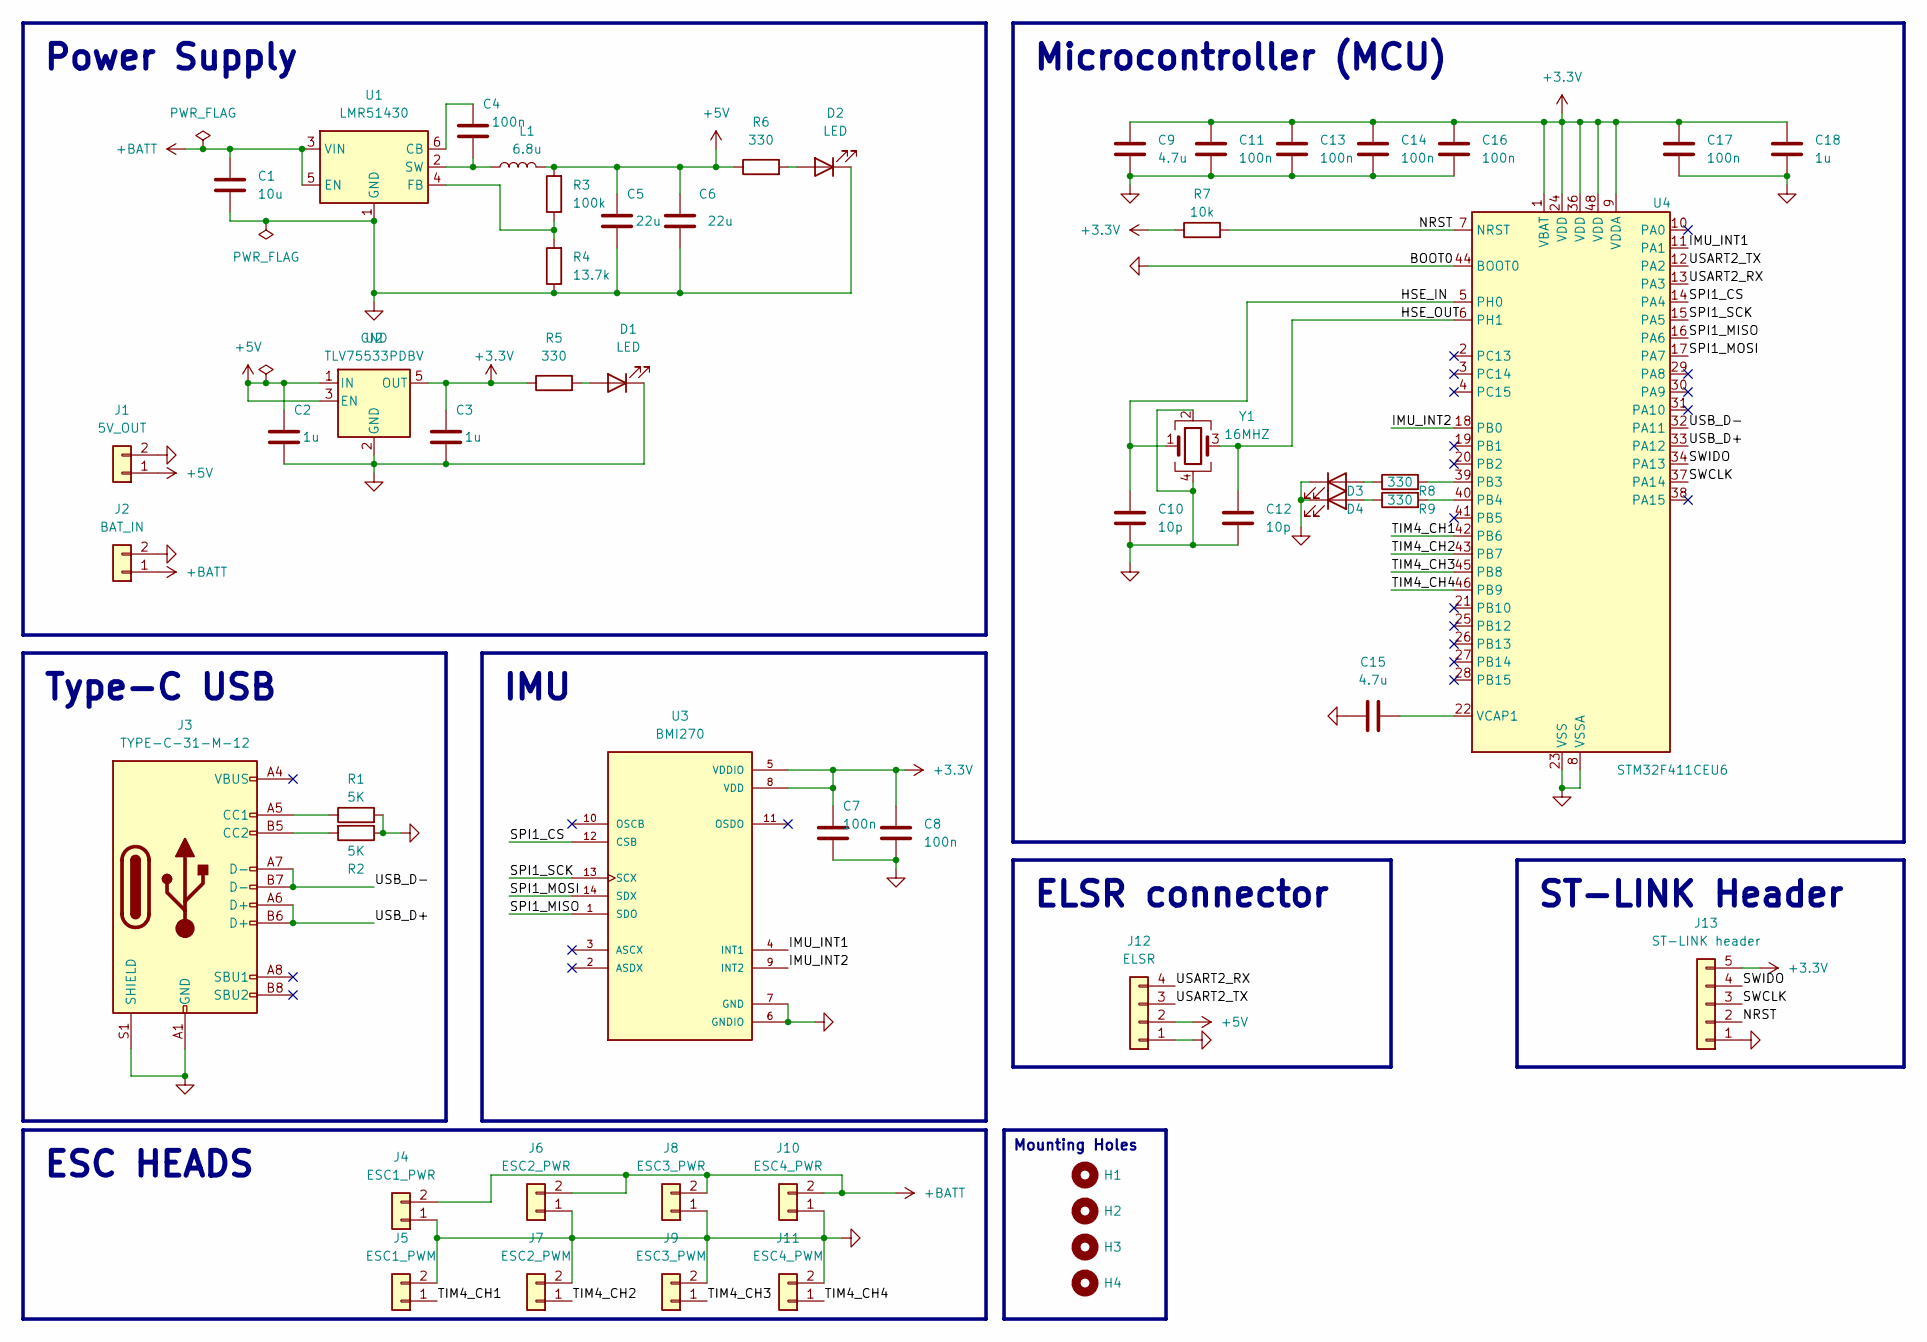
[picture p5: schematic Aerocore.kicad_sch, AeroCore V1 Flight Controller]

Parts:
C1: 10u; C_0603_1608Metric
C2, C3, C18: 1u; C_0603_1608Metric
C4, C7, C8, C11, C13, C14, C16, C17: 100n; C_0402_1005Metric
C5, C6: 22u; C_1206_3216Metric
C9, C15: 4.7u; C_0603_1608Metric
C10, C12: 10p; C_0603_1608Metric
D1, D2, D3, D4: LED; LED_0603_1608Metric
H1, H2, H3, H4: MountingHole_2.7mm
J1: 5V_OUT; Power_Pad_1.5x1.5mm
J2: BAT_IN; Power_Pad_1.5x1.5mm
J3: TYPE-C-31-M-12; USB_C_Receptacle_G-Switch_GT-USB-7010ASV
J4: ESC1_PWR; Power_Pad_2.5x3.5mm
J5: ESC1_PWM; Power_Pad_1.5x1.5mm
J6: ESC2_PWR; Power_Pad_2.5x3.5mm
J7: ESC2_PWM; Power_Pad_1.5x1.5mm
J8: ESC3_PWR; Power_Pad_2.5x3.5mm
J9: ESC3_PWM; Power_Pad_1.5x1.5mm
J10: ESC4_PWR; Power_Pad_2.5x3.5mm
J11: ESC4_PWM; Power_Pad_1.5x1.5mm
J12: ELSR; Power_Pad_4_1.5x1.5mm
J13: ST-LINK header; Solder_Pad_5_1.5x1.5mm
L1: 6.8u; L_Sunlord_MWSA0603S
R1, R2: 5K; R_0603_1608Metric
R3: 100k; R_0603_1608Metric
R4: 13.7k; R_0603_1608Metric
R5, R6, R8, R9: 330; R_0603_1608Metric
R7: 10k; R_0603_1608Metric
U1: LMR51430; SOT-23-6
U2: TLV75533PDBV; SOT-23-5
U3: BMI270; XDCR_BMI270
U4: STM32F411CEU6; QFN-48-1EP_7x7mm_P0.5mm_EP5.6x5.6mm
Y1: 16MHZ; Crystal_SMD_3225-4Pin_3.2x2.5mm

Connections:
+3.3V: C3.1, C7.1, C8.1, C9.1, C11.1, C13.1, C14.1, C16.1, C17.1, C18.1, J13.5, R5.1, R7.1, U2.5 (OUT), U3.5 (VDDIO), U3.8 (VDD), U4.1 (VBAT), U4.9 (VDDA), U4.24 (VDD), U4.36 (VDD), U4.48 (VDD)
+5V: C2.1, C5.1, C6.1, J1.1, J12.2, L1.2, R3.2, R6.1, U2.1 (IN), U2.3 (EN)
+BATT: C1.1, J2.1, J4.2, J6.2, J8.2, J10.2, U1.3 (VIN), U1.5 (EN)
/HSE_IN: C10.1, U4.5 (PH0), Y1.1
/HSE_OUT: C12.1, U4.6 (PH1), Y1.3
/IMU_INT1: U3.4 (INT1), U4.11 (PA1)
/IMU_INT2: U3.9 (INT2), U4.18 (PB0)
/NRST: J13.2, R7.2, U4.7 (NRST)
/SPI1_CS: U3.12 (CSB), U4.14 (PA4)
/SPI1_MISO: U3.1 (SDO), U4.16 (PA6)
/SPI1_MOSI: U3.14 (SDX), U4.17 (PA7)
/SPI1_SCK: U3.13 (SCX), U4.15 (PA5)
/SWCLK: J13.3, U4.37 (PA14)
/SWIDO: J13.4, U4.34 (PA13)
/TIM4_CH1: J5.1, U4.42 (PB6)
/TIM4_CH2: J7.1, U4.43 (PB7)
/TIM4_CH3: J9.1, U4.45 (PB8)
/TIM4_CH4: J11.1, U4.46 (PB9)
/USART2_RX: J12.4, U4.13 (PA3)
/USART2_TX: J12.3, U4.12 (PA2)
/USB_D+: J3.A6 (D+), J3.B6 (D+), U4.33 (PA12)
/USB_D-: J3.A7 (D-), J3.B7 (D-), U4.32 (PA11)
GND: C1.2, C2.2, C3.2, C5.2, C6.2, C7.2, C8.2, C9.2, C10.2, C11.2, C12.2, C13.2, C14.2, C15.1, C16.2, C17.2, C18.2, D1.1 (K), D2.1 (K), D3.1 (K), D4.1 (K), J1.2, J2.2, J3.A1 (GND), J3.A12 (GND), J3.B1 (GND), J3.B12 (GND), J3.S1 (SHIELD), J4.1, J5.2, J6.1, J7.2, J8.1, J9.2, J10.1, J11.2, J12.1, J13.1, R1.2, R2.1, R4.1, U1.1 (GND), U2.2 (GND), U3.6 (GNDIO), U3.7 (GND), U4.8 (VSSA), U4.23 (VSS), U4.35 (VSS), U4.44 (BOOT0), U4.47 (VSS), U4.49 (VSS), Y1.2, Y1.4
unnamed: D1.2 (A), R5.2
unnamed: D2.2 (A), R6.2
unnamed: D3.2 (A), R8.1
unnamed: D4.2 (A), R9.1
unnamed: J3.A5 (CC1), R1.1
unnamed: J3.B5 (CC2), R2.2
unnamed: C4.2, U1.6 (CB)
unnamed: R3.1, R4.2, U1.4 (FB)
unnamed: C4.1, L1.1, U1.2 (SW)
unnamed: R8.2, U4.39 (PB3)
unnamed: R9.2, U4.40 (PB4)
unnamed: C15.2, U4.22 (VCAP1)

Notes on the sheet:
Power Supply
ST-LINK Header
ESC HEADS
Mounting Holes
ELSR connector
IMU
Microcontroller (MCU)
Type-C USB

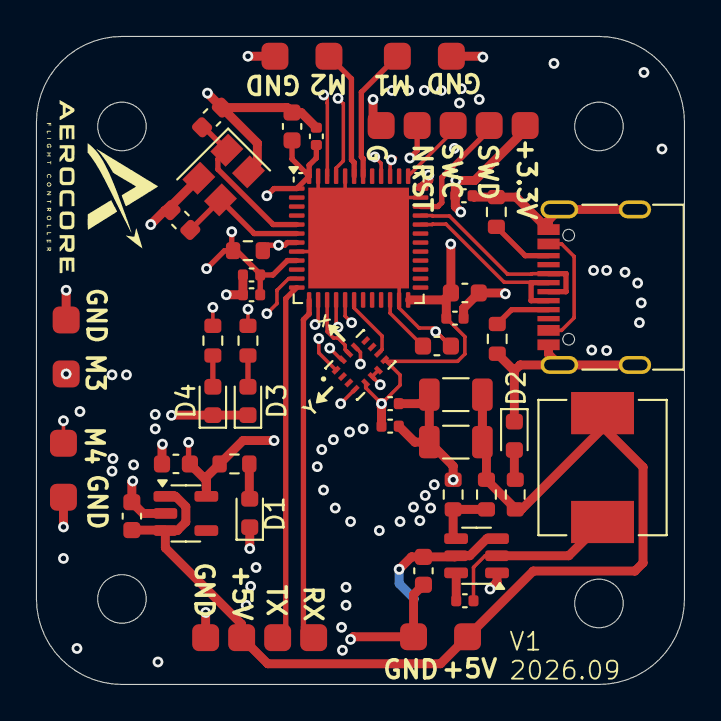
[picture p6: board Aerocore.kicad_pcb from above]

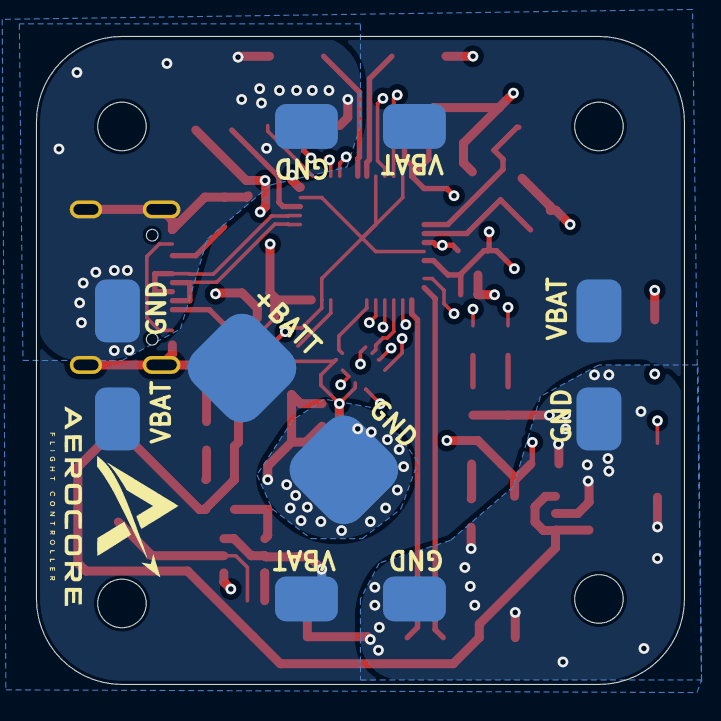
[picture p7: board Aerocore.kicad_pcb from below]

Board: 4 copper layers, 36.0 x 36.0 mm, 54 parts (5 on the bottom side), 35 nets.

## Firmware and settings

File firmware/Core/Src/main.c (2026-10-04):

#include "main.h"
#include "usb_comm.h"
#include "pid_comm.h"
#include "bmi.h"

uint8_t test;

int main(void)
{
    usb_init();
    HAL_Delay(100);

    uint8_t ok = bmi_init();
    float ax, ay, az, gx, gy, gz;


    while (1)
    {
        if (ok)
        {
        	bmi_read_accel_g(&ax, &ay, &az);
        	bmi_read_gyro_dps(&gx, &gy, &gz);

        	usb_printf("ACC(mg) %5d %5d %5d | GYR(mdps) %6d %6d %6d\r\n",
        	           (int)(ax * 1000), (int)(ay * 1000), (int)(az * 1000),
        	           (int)(gx * 1000), (int)(gy * 1000), (int)(gz * 1000));

        }
        else
        {
            usb_printf("BMI init failed\r\n");
        }
        HAL_Delay(100);
    }
}

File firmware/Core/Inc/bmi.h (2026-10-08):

/******************************************************************************
 * Copyright (C) 2026 by Mohammed Kassem
 *
 * This software is provided for educational purposes.
 *
 *****************************************************************************/
/**
 * @file bmi.h
 * @brief BMI270 IMU driver for the STM32F411
 *
 * This file contains the function declarations for the BMI270
 * accelerometer and gyroscope. The sensor is connected to SPI1
 * (PA4 = CS, PA5 = SCK, PA6 = MISO, PA7 = MOSI). The data-ready
 * interrupt pin INT1 is connected to PA1 (EXTI line 1).
 *
 * Accelerometer: +-4g (8192 LSB/g), output rate 1600 Hz
 * Gyroscope: +-250 dps (131.2 LSB/dps), output rate 1600 Hz
 *
 * Every time a new sample is ready, the BMI270 raises INT1. The
 * interrupt handler reads the sensor, stores the data and the number
 * of clock cycles since the previous sample, and sets imu_ready.
 *
 * @author Mohammed Kassem
 * @date 04/10/2026
 *
 */

#ifndef BMI_H
#define BMI_H

#include <stdint.h>

/** Size of the BMI270 configuration file in bytes */
#define BMI270_CONFIG_SIZE  8192U

/** BMI270 configuration file (defined in bmi_config.c) */
extern const uint8_t bmi270_config_file[BMI270_CONFIG_SIZE];

/** Set to 1 by the interrupt when new data is ready. Clear it after use */
extern volatile uint8_t  imu_ready;

/** CPU clock cycles (DWT->CYCCNT) since the previous interrupt */
extern volatile uint32_t imu_cycles;

/** Latest gyroscope data p, q, r in degrees per second */
extern volatile float    imu_gyro[3];

/** Latest accelerometer data ax, ay, az in g */
extern volatile float    imu_accel[3];

/**
 * @brief Sets up the SPI pins and SPI1, then reads the BMI270 CHIP_ID
 *
 * This function configures PA4-PA7, initializes SPI1 and does a
 * dummy read to switch the BMI270 from I2C to SPI mode. It then
 * reads the CHIP_ID register.
 *
 * @return CHIP_ID of the sensor (0x24 for the BMI270)
 */
uint8_t verify_bmi(void);

/**
 * @brief Initializes the BMI270
 *
 * This function checks the CHIP_ID, uploads the configuration file,
 * configures the accelerometer and gyroscope, turns them on and
 * sets up the data-ready interrupt. It must be called once at
 * startup before reading any data. The DWT cycle counter must be
 * started before calling it.
 *
 * @return 1 if the initialization worked, 0 if it failed
 */
uint8_t bmi_init(void);

/**
 * @brief Sets up the data-ready interrupt
 *
 * This function configures the BMI270 INT1 pin (active high,
 * push-pull, data-ready) and sets up PA1 as a rising edge external
 * interrupt (EXTI1). It is called by bmi_init().
 */
void bmi_int_init(void);

/**
 * @brief Interrupt handler for EXTI line 1 (BMI270 INT1)
 *
 * This function runs every time a new sample is ready. It stores
 * the clock cycles since the last interrupt in imu_cycles and
 * resets the cycle counter. It then reads the accelerometer and
 * gyroscope into imu_accel and imu_gyro and sets imu_ready to 1.
 */
void EXTI1_IRQHandler(void);

/**
 * @brief Reads one BMI270 register
 *
 * @param reg Register address
 * @return Value of the register
 */
uint8_t bmi_read_reg(uint8_t reg);

/**
 * @brief Writes one BMI270 register
 *
 * @param reg Register address
 * @param value Value to write
 */
void bmi_write_reg(uint8_t reg, uint8_t value);

/**
 * @brief Reads multiple BMI270 registers in one transaction
 *
 * The dummy byte that the BMI270 sends first during an SPI read
 * is discarded.
 *
 * @param reg Address of the first register
 * @param data Buffer to store the data
 * @param len Number of bytes to read
 */
void bmi_read_burst(uint8_t reg, uint8_t *data, uint32_t len);

/**
 * @brief Uploads the configuration file to the BMI270
 *
 * The BMI270 needs this file after every power up or reset,
 * otherwise the sensor data stays at zero.
 */
void bmi_load_config(void);

/**
 * @brief Reads the raw accelerometer data
 *
 * @param x Raw X value (8192 LSB/g)
 * @param y Raw Y value (8192 LSB/g)
 * @param z Raw Z value (8192 LSB/g)
 */
void bmi_read_accel(int16_t *x, int16_t *y, int16_t *z);

/**
 * @brief Reads the raw gyroscope data
 *
 * @param x Raw X value (131.2 LSB/dps)
 * @param y Raw Y value (131.2 LSB/dps)
 * @param z Raw Z value (131.2 LSB/dps)
 */
void bmi_read_gyro(int16_t *x, int16_t *y, int16_t *z);

/**
 * @brief Reads the accelerometer data in g
 *
 * @param x X acceleration in g
 * @param y Y acceleration in g
 * @param z Z acceleration in g
 */
void bmi_read_accel_g(float *x, float *y, float *z);

/**
 * @brief Reads the gyroscope data in degrees per second
 *
 * @param x X angular rate in dps
 * @param y Y angular rate in dps
 * @param z Z angular rate in dps
 */
void bmi_read_gyro_dps(float *x, float *y, float *z);

#endif /* BMI_H */

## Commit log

2026-09-02 Design schematic and assign footprints
    [Aerocore.kicad_pcb, Aerocore.kicad_sch]
2026-09-05 PCB Design
    [Aerocore.kicad_pcb]
2026-09-07 Redesign PCB layout to fix power distribution issues
    [Aerocore.kicad_pcb, BMI270.step, HRO_TYPE-C-31-M-12.step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]
2026-09-08 Add PCB layout reference design notes, issues and decisions made
    [V1_Aerocore.kicad_pcb]
2026-09-08 Change KiCAD to version 7
    [Aerocore.kicad_pcb]
2026-09-08 Add manufacturing files (bom and cpl) + final drc output
    [bom.csv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]
2026-09-30 Update README with PCB image
2026-10-04 Add BMI270 driver: SPI, config upload, accel and gyro reading
2026-10-08 Add data-ready interrupt to bmi driver
2026-10-08 Reset DWT to 0 after completed init
    [bmi.c]
2026-10-08 Add extended kalman filter for imu sensor fusion
2026-10-09 Add uart2 init and read func
2026-10-09 Add interrupt handler to uart
2026-10-10 Add pwm controller
2026-10-10 Change PWM frequency to 400HZ
2026-10-10 Set imu interrupt priority to 1
2026-10-10 Fix interrupt priority issue
2026-10-10 Add PID control
2026-10-10 Add conntrol algorithm and motor mixer
2026-10-23 Change acc & gyro to 800HZ. 1600HZ is very sensitive to noise
2026-10-23 Change Motor Spining direction comments & Update Motor Mixer
2026-10-23 Fix the DISARM logic and update PID gains
2026-10-23 dd CRSF attitude telemetry transmission + uart2 send function
2026-10-24 Add telematry + FM frame transmission to radio controller. Enable the adjusments of PID gains
